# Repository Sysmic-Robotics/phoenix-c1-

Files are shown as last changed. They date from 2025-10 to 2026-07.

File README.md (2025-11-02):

# Phoenix-C1 — Driver modular para motor PMSM (RoboCup SSL)

Proyecto ELO301 — Sysmic Robotics  
Controlador modular para cada motor del robot, con ruta de actualización a FOC y mantenimiento sencillo en competencia. :contentReference[oaicite:0]{index=0}

---

## Estado del proyecto
- ✅ **Esquemáticos**: prácticamente completos; arquitectura modular por motor.
- 🚧 **PCB/Firmware**: siguiente hito inmediato (ver Cronograma del documento).
- 🎯 **Objetivo de costo**: ~20–30 USD/unidad (FOC-capable). :contentReference[oaicite:1]{index=1}

---

## Motivación y alcance
La placa “todo-en-uno” actual es frágil: una falla deja inoperante el sistema. Phoenix-C1 separa el control por motor para elevar confiabilidad, facilitar recambios y habilitar control avanzado (FOC) más adelante. :contentReference[oaicite:2]{index=2} :contentReference[oaicite:3]{index=3}

---

## Arquitectura del sistema (resumen)
- **MCU**: STM32G431CBU6 (control + PWM).
- **Gate driver**: DRV8323S.
- **Etapa de potencia**: 3 medios puentes con 6× MOSFET NTMFS5C612NLT1G.
- **Encoder**: AS5600 (I²C).
- **Alimentación lógica**: 3.3 V (buck).
- **Bus de potencia**: +V 10–40 V (diseño), pensado para baterías 6S/24 V del robot. :contentReference[oaicite:4]{index=4} :contentReference[oaicite:5]{index=5}

**Interfaces clave**
- I²C (AS5600), SPI (config/telemetría DRV8323S), SPI esclavo para consignas externas, PWM hacia DRV8323S, GPIO/EXTI y LED de estado. :contentReference[oaicite:6]{index=6}

---

## Firmware (V1)
- **Lazo**: control básico de velocidad con realimentación del encoder.
- **FOC**: previsto para actualización de firmware futura (hardware ya cableado). :contentReference[oaicite:7]{index=7}

**Módulos**
- Referencia/entrada (SPI esclavo), adquisición de velocidad (AS5600), generador PWM (TIMx), driver DRV8323S (config y fallas), temporización/SysTick. :contentReference[oaicite:8]{index=8}

**Flujo**
1. Init de periféricos (GPIO, TIM, I²C/SPI, PWM, DRV8323S deshabilitado).
2. Espera de referencia válida (sondeo cada 0.5 ms).
3. Lectura de velocidad (encoder).
4. Cálculo de control y actualización de duty en 3 fases.
5. Conmutación vía DRV8323S y realimentación. :contentReference[oaicite:9]{index=9}

---

## Pruebas planificadas
- **Elementos**: power-up +V∈[10,40] V, 3.3 V estable, rizado a f_PWM, separación de masas; validación SPI/I²C/PWM/GPIO. :contentReference[oaicite:10]{index=10}  
- **Funcionalidades**: arranque y control de velocidad; inyección de fallas (UVLO, nFAULT, kill-switch) y recuperación segura. :contentReference[oaicite:11]{index=11}

---

## Restricciones físicas y entorno
- **PCB** máx. 4×4 cm (montaje en el centro de motores ∅≈5 cm tipo 5010).  
- **Rango térmico** típico de competencias indoor; tolerancia a impactos moderados (carcasa plástica/impresa 3D). :contentReference[oaicite:12]{index=12}

---

## Costos (referencia)
- Meta ≈ 20–30 USD/unidad con capacidad FOC (24 drivers totales objetivo). :contentReference[oaicite:13]{index=13}  
- **BOM parcial** (ejemplo en CLP con 6 MOSFET): STM32G431, DRV8323S, NTMFS5C612NLT1G×6, AS5600, MAX15062 buck, PCB 4 capas, pasivos. :contentReference[oaicite:14]{index=14}

---

## Puesta en marcha (high-level)
1. Ensamblar y verificar 3.3 V, continuidad y ausencia de cortos.
2. Flashear firmware base (SWD/J-Link/ST-Link).
3. Probar SPI con DRV8323S (ID y registros), lectura AS5600 y PWM.  
4. Activar control de velocidad con consignas de prueba (escalón/rampa). :contentReference[oaicite:15]{index=15}

---

## Equipo
- Rodrigo Sierra, Gabriel Arcaya, Sebastián Pinochet — ELO301 (UTFSM). :contentReference[oaicite:16]{index=16}

---

## Licencia
Define la licencia aquí (MIT/BSD/GPL) según necesidades del curso/proyecto.

---

## Agradecimientos
Cátedra ELO301 y referentes tecnológicos (p. ej., drivers FOC comerciales tomados como benchmark de costo/desempeño). :contentReference[oaicite:17]{index=17}

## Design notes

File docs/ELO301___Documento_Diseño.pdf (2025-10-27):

Departamento de Electrónica Universidad Técnica Federico Santa María

# Documento de Diseño

# “Phoenix-C1” — Control de motor AC

## Proyecto ELO301

Fecha | Revisión | Autor | Comentarios
03/10/2025 | 1.0 | Rodrigo Sierra, Sebastián Pi-nochet, Gabriel Arcaya | Primera versión del documento de diseño.

## Índice general

1. Introducción | 3
2. Funcionalidades identificadas | 3
3. Elementos identificados | 3
4. Diseño de hardware propuesto | 4
4.1. Diagrama de bloques | | 4
4.2. Detalle por bloque | | 5
5. Diseño de firmware propuesto | 6
5.1. Detalle de drivers | | 6
5.2. Diagrama de flujo | | 6
5.3. Detalle por módulo | | 7
6. Pruebas | 8
6.1. Prueba sobre elementos | | 8
6.2. Prueba sobre funcionalidades | | 8
7. Cronograma | 9
8. Costos | 9

## Índice de imágenes

1. | Diagrama de bloques | | 5
2. | Diagrama de Flujo para el firmware | | 7

## 1. Introducción

El proyecto aborda la mejora del sistema de control de motores en un robot de competencia de la categoría RoboCup SSL. La arquitectura vigente integra en una única placa maestra la CPU, los giroscopios, los drivers de potencia, el módulo de radio y la gestión de energía, configuración que ha demostrado ser frágil: la falla o el desplazamiento de un componente compromete la operatividad completa de la placa. Para mitigar este riesgo, se propone una estrategia de modularización en la cual cada motor dispone de una placa de control independiente. Esta aproximación eleva la confiabilidad, facilita el mantenimiento en competencia y habilita la adopción progresiva de esquemas de control avanzados.
En una primera etapa, se priorizará el uso de un encoder magnético para implementar un lazo de control de velocidad simple y confiable. En paralelo, se dejarán previstas las conexiones físicas (sensado de corrientes y voltajes de fase, referencias de posición y sincronía, e interfaces de comunicación pertinentes) con el fin de habilitar, mediante una futura actualización de firmware, la implementación de control orientado por campo (FOC) sobre motores síncronos de imanes permanentes (PMSM), mejorando el desempeño dinámico y la eficiencia del actuador.

## 2. Funcionalidades identificadas

A partir del análisis del marco de referencia y de las correcciones al documento de especificaciones, se identifican las siguientes funcionalidades requeridas:
Sensado de velocidad y/o posición mediante encoder (preferentemente magnético).

Conmutación trifásica mediante driver de compuerta para MOSFET.

Control básico para el accionamiento de un PMSM con posibilidad de evolución a FOC.

Interfaces de comunicación SPI para enlace con una unidad central.

Capacidades de diagnóstico: monitoreo de corrientes de fase y tensión de alimentación.

## 3. Elementos identificados

Para materializar las funcionalidades anteriores, se identifican los siguientes elementos de diseño y hardware:
Controlador principal: microcontrolador de la familia STM32 para lazo de control y comunicaciones.

Etapa de potencia: puente trifásico con MOSFET y driver de compuerta dedicado.

Sensado: resistencias shunt para corriente y encoder magnético para posición/velocidad.

Alimentación y protección: convertidores DC–DC para rieles lógicos y salvaguardas frente a sobrecorriente/sobretensión.

Comunicación: conectividad externa mediante SPI hacia la CPU principal.

Firmware: algoritmo de control para PMSM con ruta de actualización hacia FOC y parametrización en campo.

## 4. Diseño de hardware propuesto

### 4.1. Diagrama de bloques

El sistema se organiza en dos dominios: control y sensado (lógica a +3,3 V) y potencia (bus +V puede ser entre 10V a 40V). El microcontrolador STM32G431CBU6 coordina la conmutación del inversor trifásico y la adquisición de señales. La etapa de potencia la componen el gate driver DRV8323S y seis MOSFET NTMFS5C612NLT1G en tres medio-puentes que alimentan un PMSM. La corriente de fase se mide con un resistor shunt de baja impedancia en el retorno. Un AS5600 entrega la posición del rotor por bus I²C.

Buses y direcciones de señal:
I

2C bidireccional (ENC SDA, ENC SCL): el MCU actúa como maestro y el codificador AS5600 como esclavo; el flujo útil de datos es sensor→MCU.

SPI con roles diferenciados:
- DRV8323S (MCU maestro): SPI MOSI (MCU→DRV), SPI MISO (DRV→MCU), SPI SCK (MCU→DRV), GD CS (MCU→DRV, activo-bajo). Uso: configuración, telemetría y diagnóstico de fallas.
- Conector de referencia de velocidad (MCU esclavo): REF MOSI (Maestro externo→MCU), REF MISO (MCU→Maestro externo), REF SCK (Maestro externo→MCU), REF CS (Maestro externo→MCU, activo-bajo). Uso: recepción de consignas y, opcionalmente, envío de telemetría bajo petición.

PWM unidireccional (MOTOR1, MOTOR2, MOTOR3) desde el MCU hacia el DRV8323S para la modulación
de compuertas (p. ej., SVPWM).

GPIO/EXTI: líneas INT1 y INT2 reservadas para interrupciones de eventos externos; salida LED para señalización de estados.

Dominio de potencia: el Power Supply Connector entrega el bus +V a la etapa de potencia y a la entrada del Power Management (Buck), que regula a +3,3 V para lógica, sensores y señales de control, separando los dominios de potencia y lógica.

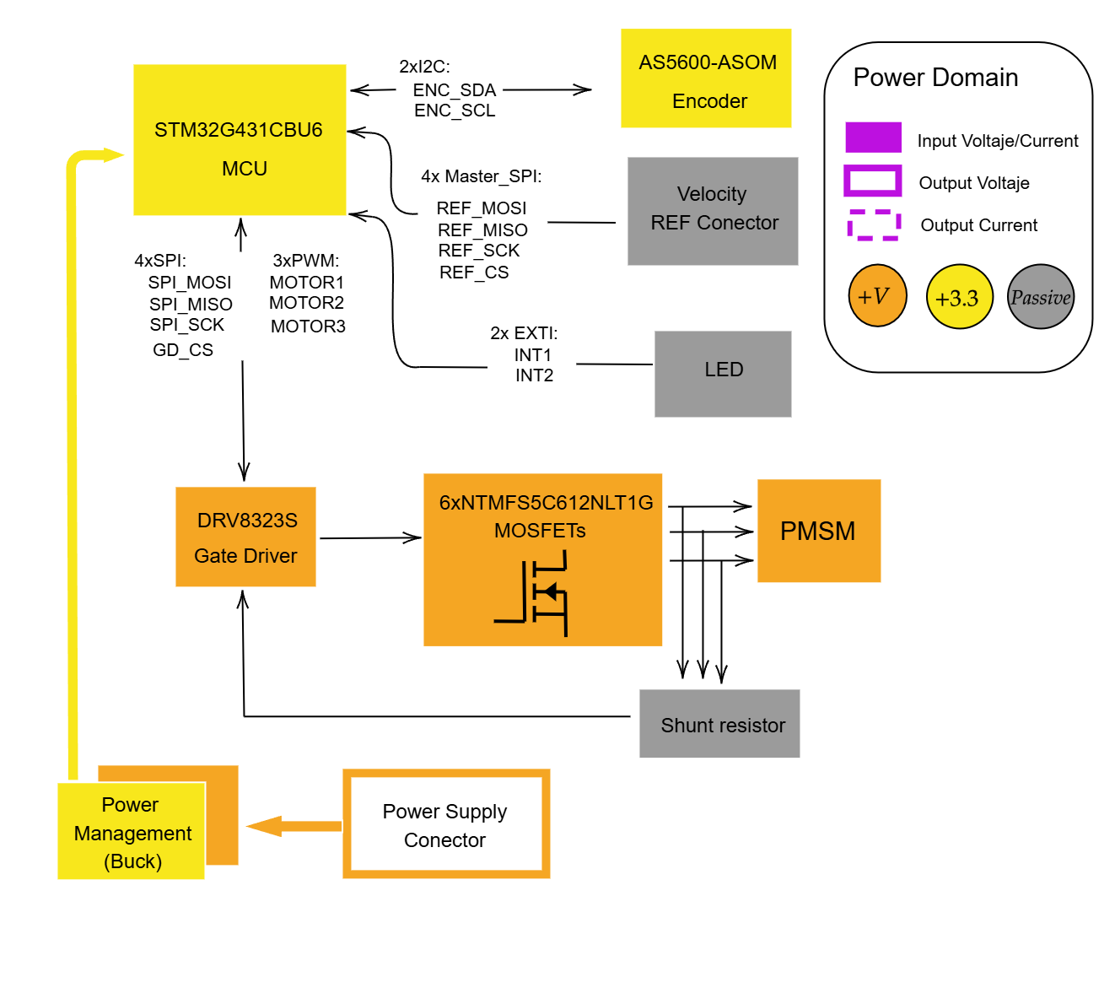
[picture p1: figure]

Illustration 1: Diagrama de bloques

### 4.2. Detalle por bloque

Bloque 1: Control y sensado (MCU, AS5600 e interfaces) El STM32G431CBU6 genera tres señales PWM (MOTOR1{3) para accionar el inversor a través del DRV8323S. Mantiene dos enlaces SPI con roles diferenciados: (i) MCU como maestro hacia el DRV8323S
SPI MOSI, SPI MISO, SPI SCK, GD CS
para configuración y diagnóstico; (ii) MCU como esclavo en el bus de referencia de velocidad
REF MOSI (entrada al MCU), REF MISO (salida del MCU), REF SCK (entrada), REF CS (entrada activabaja)
, donde un maestro externo envía consignas. La posición/velocidad del rotor se adquiere por un bus I²C bidireccional con el AS5600

ENC SDA, ENC SCL
, operando el MCU como maestro. Además, se disponen dos líneas de interrupción externa

INT1, INT2
para eventos asincrónicos y una salida LED para señalización de estado. Todo el bloque funciona a +3,3 V provistos por el regulador buck.

Bloque 2: Potencia y conversión de energía (DRV8323S, MOSFETs, PMSM y alimentación) El DRV8323S recibe las señales PWM del MCU y conmuta seis MOSFET NTMFS5C612NLT1G dispuestos en tres medio-puentes para conformar un inversor trifásico que alimenta el PMSM. El gate driver gestiona la habilitación, los tiempos muertos y la protección, y expone el estado por SPI y/o pines de falla dedicados. El Power Supply Connector introduce el bus +V a la etapa de potencia y al Power Management (Buck), que regula a +3,3 V para la electrónica de control, manteniendo separados los dominios de potencia y lógica.

Bloque 3: Sensado de corriente (hardware presente; deshabilitado en esta versión) El trayecto de sensado de corriente mediante resistor shunt y acondicionamiento analógico se encuentra implementado a nivel de hardware y cableado al DRV8323S/ADC del MCU. No obstante, no será utilizado por el firmware inicial: por restricciones de tiempo no se implementará control FOC ni lazos de corriente (ni id ni iq). La primera versión ejecutará control simple de velocidad basado únicamente en realimentación del encoder. El sensado de corriente y el FOC quedarán planificados como actualización futura del firmware, reutilizando el hardware existente sin cambios en la placa.

## 5. Diseño de firmware propuesto

### 5.1. Detalle de drivers

El firmware se organiza en controladores de bajo nivel asociados a cada elemento del sistema: Driver de comunicaciones para referencia: módulo de recepción de consignas desde el exterior. Entrega una bandera de referencia válida y el valor de consigna.

Temporización: temporizador/SysTick para retardos y planificación de tareas; se utiliza un sondeo con espera de 0,5 ms cuando no hay referencia disponible.

Encoder: adquisición de posición/velocidad del motor a través del sensor de posición. Expone la velocidad filtrada al lazo de control.

Driver PWM (TIMx): generación de tres salidas PWM para el inversor trifásico. Permite habilitar/deshabilitar el puente y actualizar el ciclo útil en tiempo real.

Driver del gate driver (DRV8323S): interfaz de configuración y diagnóstico del controlador de compuertas; aplica las órdenes de encendido/apagado y supervisa el estado de fallas.

Driver de GPIO de estado: control de indicadores (LED) y líneas de interrupción si corresponde.

### 5.2. Diagrama de flujo

El flujo funcional se resume en los siguientes pasos:
1. Inicio: inicialización de temporizadores, GPIO, comunicaciones, encoder, PWM y gate driver (salidas deshabilitadas).
2. Recepción de referencia: si no existe una referencia válida, se espera 0,5 ms y se repite el sondeo.
3. Lectura de velocidad: una vez disponible la referencia, se obtiene la velocidad del motor desde el encoder.
4. Cálculo en STM32: se ejecuta el cómputo de variables de control y se determina el ciclo útil de PWM para las tres fases.
5. Accionamiento: se actualizan las salidas PWM; el gate driver DRV8323S conmuta los MOSFET del inversor.
6. Ejecución y realimentación: el motor gira, se cierra el bucle mediante la nueva lectura del encoder y se regresa al paso de cálculo.

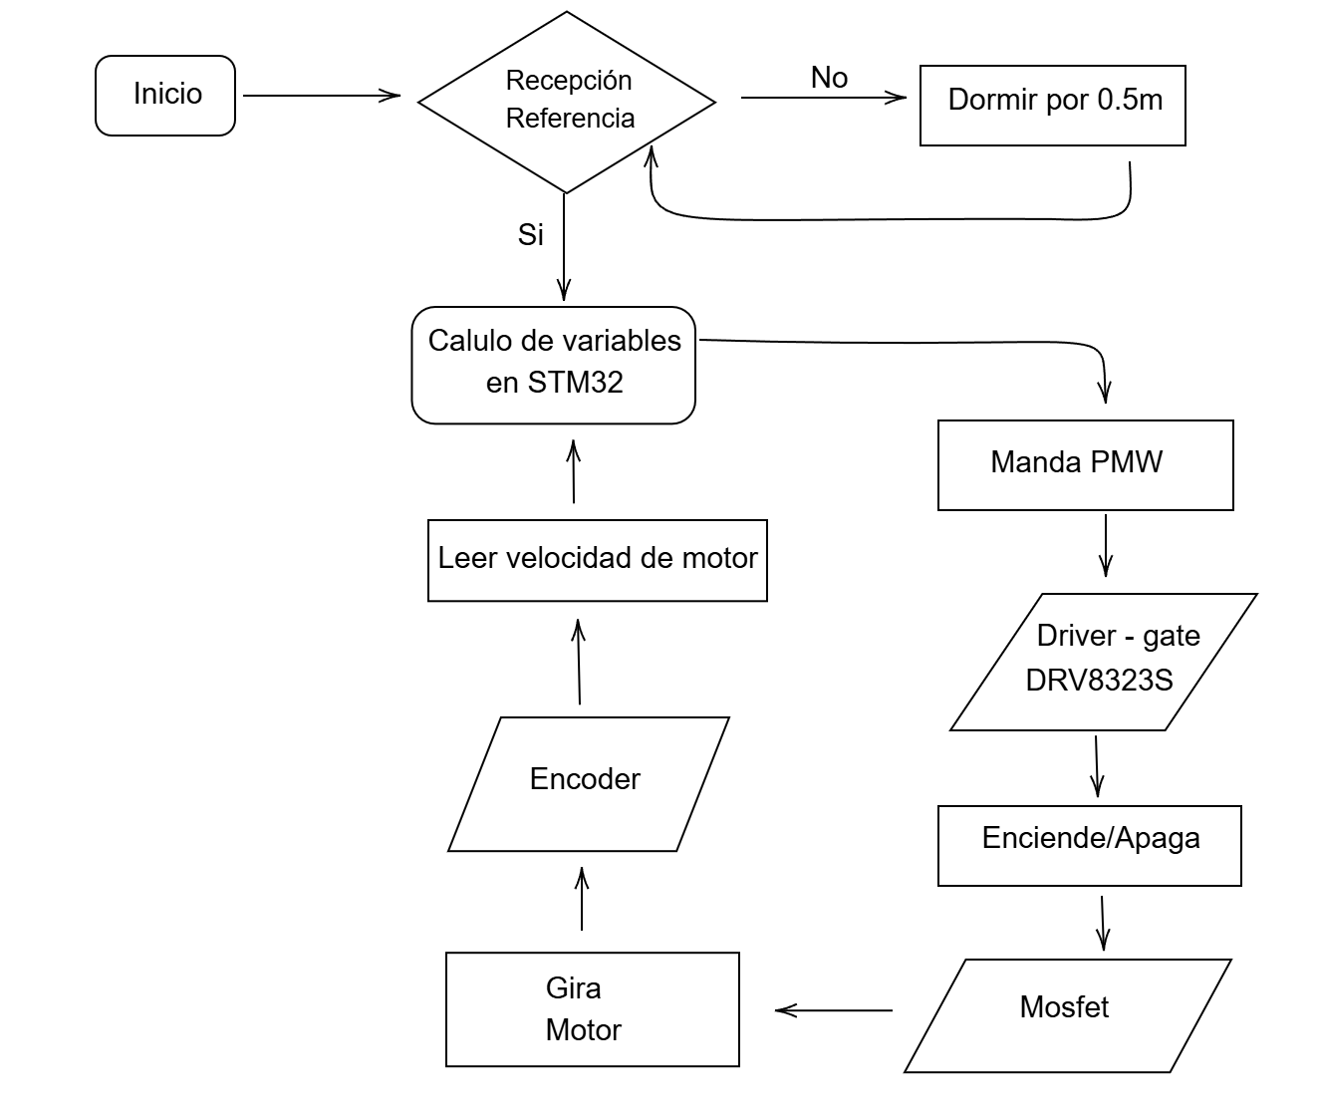
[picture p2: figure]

Illustration 2: Diagrama de Flujo para el firmware

### 5.3. Detalle por módulo

Módulo 1: Adquisición y referencia Este módulo gestiona la llegada de la consigna externa y la medición de la velocidad del motor. Implementa el sondeo con espera de 0,5 ms cuando no hay referencia, convierte la posición del encoder en velocidad utilizable por el control y publica los datos al scheduler. Sus principales interfaces son: entrada de Referencia (comunicación), entrada de Encoder y salida de Velocidad estimada más la bandera de Referencia válida.

Módulo 2: Control y actuación Este módulo ejecuta el cálculo en el STM32 para obtener el ciclo útil de las tres fases y actualiza el generador PWM. Coordina el encendido/apagado del gate driver DRV8323S y, por ende, la conmutación de los MOSFET. Sus interfaces son: entradas de Referencia y Velocidad, salidas PWM A/B/C hacia el gate driver y líneas de estado/diagnóstico para supervisión.

## 6. Pruebas

### 6.1. Prueba sobre elementos

Prueba 1 Integridad eléctrica y alimentación. Se alimenta el bus +V ∈ [10, 40] V y se verifica la regulación de +3,3 V en arranque y régimen, el rizado a la frecuencia fPWM y la correcta separación de masas de potencia y lógica; como metas prácticas se considera V3,3.

Prueba 2 Interfaces digitales y señalización. Se valida el SPI con el DRV8323S (MCU como maestro: lectura/escritura de registros, ID y banderas), el SPI de referencia (MCU como esclavo: REF CS activo-bajo, recepción de consignas), el I²C con el AS5600 (lectura de ángulo/velocidad), la generación PWM (frecuencia y resolución) y las GPIO/EXTI de estado.

### 6.2. Prueba sobre funcionalidades

Prueba 1 Arranque y control de velocidad en lazo cerrado sin FOC. Con el DRV8323S habilitado, se aplican referencias tipo escalón y rampa dentro del rango operativo, registrando referencia, velocidad del encoder, ciclo útil y estado del driver para distintos niveles de +V .

Prueba 2 Gestión de fallas y seguridad funcional. Se induce UVLO, se fuerza nFAULT y se acciona el kill-switch lógico para comprobar deshabilitación inmediata de PWM, registro/notificación de la causa y recuperación controlada.

## 7. Cronograma

El cronograma se compacta en cuatro bloques quincenales más la entrega aproximada, cubriendo desde el 13 de octubre hasta el 1 de diciembre de 2025. Las columnas representan ventanas de trabajo con solapamientos controlados.

13–26 Oct | 27 Oct–9 Nov | 10–23 Nov | 24–30 Nov | 1 Dic

Diseño
esquemático

X

Diseño PCB | X | X

Compra
componentes
| X

Compra y envío de
PCB
| X
Integración | X | X

Desarrollo
firmware
| X | X | X
Pruebas | X | X

Documentación y
entrega
| | | X | X

Tabla 1: Cronograma compacto hasta la entrega del 1 de diciembre de 2025.

## 8. Costos

Descripción (por driver) | 1 unidad [CLP] | 100 unidades [CLP]
STM32G431CBU6 (1×) | $5,667 | $361,800
DRV8323S (gate driver, 1×) | $3,998 | $248,600
NTMFS5C612NLT (MOSFET, 6×) | $13,374 | $636,600
AS5600–ASOM (encoder, 1×) | $3,192 | $208,300
MAX15062BATA+T (dc-dc buck, 1×) | $2,442 | $189,300
PCB 4×4 cm, 4 capas + envío (1×) | $10,000 | $1,000,000
Pasivos y reguladores (R, C, etc.) | $3,000 | $300,000
Total (BOM parcial) | $41,673 | $2,944,600

Tabla 2: Costos por componente en CLP. Los valores provienen de Mouser y consideran 6 MOSFET por driver. Proyección lineal a 100 unidades, con descuentos por volumen.

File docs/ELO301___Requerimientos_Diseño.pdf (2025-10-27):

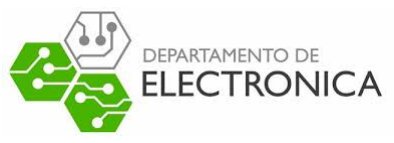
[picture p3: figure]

# Documento de Especificaciones

## Control de motor AC

## Fecha 23 de octubre de 2025 Integrantes: Rodrigo Sierra Gabriel Arcaya Sebastian Pinochet Asignatura: ELO301 Profesor: Alvaro Aguirre ´

## Índice

1 Identificación del cliente | 4
2 Nombre del Equipo | 4
3 Marco de Referencia | 4
4 Funcionalidad requerida y/o identificada | 4
5 Alimentación Utilizada | 5
6 Empaquetamiento del equipo | 5
7 Características del Medio donde Será Utilizado | 6
8 Costos Objetivos del Proyecto | 6
9 Certificaciones a Cumplir | 6
10 Requerimientos Especiales | 6

ELO301 | 2025

## Registro de Especificaciones

Nombre del Proyecto: Control Motor AC

Fecha | Revisión | Autor | Comentarios
29/08/2025 | 1.0 | Rodrigo Sierra, Gabriel Arcaya, Sebastián Pinochet | Revisión inicial
USM | 3

## 1. Identificación del cliente

### 1.1. Fecha del Requerimiento

La fecha de cumplimiento del requerimiento se establece para el final del semestre académico, lo que corresponde aproximadamente a un plazo de 14 semanas.

### 1.2. Nombre del mandante

Alvaro Aguirre

### 1.3. Persona de contacto

Alvaro Aguirre

### 1.4. Datos de contacto

alvaro.aguirre@gmail.com

## 2. Nombre del Equipo

Sysmic Robotics

## 3. Marco de Referencia

El problema identificado corresponde a la mejora del sistema de control de los motores de un robot de competencia de la categoría RoboCup SSL. En la actualidad, se utiliza una placa maestra que integra en un único circuito la CPU, los giroscopios, los drivers de potencia, el módulo de radio y la gestión de energía. Esta arquitectura monolítica ha generado dificultades en el montaje y mantenimiento, dado que la falla o el desplazamiento de un solo componente inutiliza la totalidad de la placa, dejándola inoperante y no apta para la competencia.

Con el fin de superar estas limitaciones, se propone una estrategia de modularización, en la cual cada motor contará con una placa independiente para su control. Esta aproximación permite aumentar la confiabilidad del sistema y, al mismo tiempo, ofrece la oportunidad de implementar un esquema de control más preciso. En particular, se plantea el uso de motores PMSM controlados mediante la técnica de Control Orientado por Campo (FOC), la cual garantiza un desempeño dinámico superior y un mayor aprovechamiento de las capacidades del actuador.

## 4. Funcionalidad requerida y/o identificada

### 4.1. Principales funcionalidades que debe cumplir el sistema

El sistema debe garantizar un control robusto y eficiente de los motores del robot de competencia, asegurando estabilidad y confiabilidad en escenarios de alta exigencia como la RoboCup SSL. Las principales funcionalidades requeridas son:

Sensado de velocidad mediante un encoder.

Utilización de un driver para la conmutación de MOSFET.

Control básico para lograr movimiento de un motor síncrono de imanes permanentes (PMSM) con posibilidad de mejora futura a control basado en campo (FOC).

Interfaz de comunicación SPI y UART para posibilidad de comunicación con una unidad central.

Capacidad de diagnóstico básico (monitoreo de corriente y voltaje).

### 4.2. Principales elementos que debe incorporar el sistema

Para cumplir las funcionalidades definidas, el sistema debe integrar los siguientes elementos físicos y de diseño:

Controlador principal: basado en microcontrolador STM32 para control de motores.

Etapa de potencia: puente trifásico con MOSFETs y drivers de compuerta dedicados.

Sensado: sensores de corriente (shunt) y sensores de posición (encoder magnético).

Alimentación: convertidores DC-DC y sistema de protección.

Comunicación: Posibilidad de comunicación externa con interfaz estándar (SPI, UART) para una CPU principal.

Firmware: Algoritmo básico para la generación de movimiento en un motor síncrono de imanes permanentes (PMSM, Permanent Magnet Synchronous Motor ), con la posibilidad de una futura implementación de control por orientación de campo (FOC) y ajuste de parámetros.

## 5. Alimentación Utilizada

La alimentación del sistema se establece en 24 V, correspondiente al voltaje utilizado en la placa principal. Además, se emplean baterías con características similares, cuya tensión nominal es de 22, 2 V. En particular, se consideran dos modelos principales, entre ellos la batería CNHL de 22, 2 V, 100C, 6s, con una capacidad de 1300 mAh y una energía de 28, 86Wh.

## 6. Empaquetamiento del equipo

### 6.1. Límites de Tamaño

El equipo ”Sysmic Robotics”decidió reemplazar los motores EC-45 de Maxon debido a su alto costo, priorizando la reducción de gastos de producción frente a la categoría SSL. Como alternativa, se seleccionaron motores brushless de imanes permanentes adquiridos en AliExpress (modelos 5010 de 360KV y 750KV, costo aproximado de 16 USD), originalmente diseñados para multicópteros. Con un diámetro cercano a 5 cm, estos motores imponen la restricción de diseñar el driver con dimensiones máximas de 4 × 4 cm para su instalación en el centro del motor.

### 6.2. Grado de Protección

El sistema debe disponer de un nivel de protección adecuado que garantice su funcionamiento en entornos de competencia:

Protección mecánica: Se considera suficiente un encapsulado que prevenga daños ocasionados por golpes o vibraciones.

### 6.3. Geometría del Equipo

La geometría se define por las dimensiones y el volumen ocupado por el sistema. En dispositivos de control para robots de competencia se consideran:

Dimensiones del PCB: tamaño máximo de 4 × 4 cm para permitir su montaje en el centro del motor.

Espesor: placas de 1,6 mm con posibilidad de 4 capas de cobre.

Forma: diseño cuadrado que facilite una sujeción firme mediante tornillos al sistema.

Conectividad: conectores laterales que faciliten el cableado interno del robot.

### 6.4. Materiales a Utilizar

La selección de materiales debe asegurar resistencia mecánica, estabilidad térmica y buena conductividad eléctrica. Para este tipo de sistemas se consideran:

Sustrato de PCB: FR4 de alta calidad para aplicaciones electrónicas estándar.

Cobre: espesor de 1 oz/ft² para las pistas de potencia.

Carcasa: estructura plástica ligera PLA impreso en 3D para el montaje.

### 6.5. Interfaz Física con el Usuario

La interfaz física debe permitir la interacción básica entre el operador y el sistema de control del motor, facilitando el montaje, configuración y monitoreo en condiciones de competencia. Los elementos considerados son:

Conectores de potencia: terminales para la conexión de las baterías de 24 V y de las fases del motor PMSM.

Conectores de señal: pines o headers dedicados para comunicación con la CPU principal (SPI, UART).

Pads de programación: interfaz física para grabar o depurar el firmware (ej. SWD o JTAG).

## 7. Características del Medio donde Será Utilizado

### 7.1. Temperatura Ambiental

El sistema debe operar en condiciones de temperatura moderada, típicas de entornos cerrados donde se desarrollan las competencias RoboCup. Se considera un rango de funcionamiento entre 10◦C y 40◦C, con tolerancia a incrementos locales debido a la disipación térmica de los componentes electrónicos.

### 7.2. Golpes y Vibraciones

El dispositivo debe soportar impactos moderados derivados de choques entre robots o con el balón, habituales en el contexto competitivo. Se considera el uso de carcasa protectora de plástico ABS o impresión 3D en PLA reforzado, capaz de absorber energía de impacto sin comprometer el funcionamiento electrónico.

## 8. Costos Objetivos del Proyecto

El equipo indicó que el costo aproximado de producción de un driver basado en el integrado L623SPD es de 18 USD; sin embargo, dicho diseño no cumple con el desempeño esperado. Como referencia tecnológica se considera el módulo Moteus C1, que implementa control FOC, aunque su precio de adquisición es de 70 USD por unidad, lo cual resulta poco viable económicamente.
En este contexto, el objetivo del proyecto es desarrollar un driver con capacidad de control FOC cuyo costo de producción se sitúe en torno a los 20 ∼ 30 USD por unidad. Esta meta responde a la necesidad de fabricar un total de 24 drivers (cuatro por cada robot), considerando un mínimo de seis robots en operación. Alcanzar este umbral de costos permitirá mantener la competitividad frente a equipos rivales que emplean componentes de menor precio, sin comprometer el rendimiento requerido en competencia.

## 9. Certificaciones a Cumplir

Dado que el presente desarrollo corresponde a un producto de carácter experimental y de testeo, no se priorizará la obtención formal de certificaciones. Sin embargo, el diseño del driver tomará como referencia normativas y buenas prácticas de seguridad eléctrica y compatibilidad electromagnética, con el fin de asegurar un nivel básico de robustez y confiabilidad.

## 10. Requerimientos Especiales

Además de los criterios funcionales básicos, el sistema debe contemplar requerimientos adicionales que faciliten su operación y mantenimiento en el entorno de competencia:

Mantenimiento rápido: facilidad de reemplazo de módulos en caso de falla durante el torneo.

Modularidad: independencia de cada driver para minimizar el impacto de fallas aisladas.

Protección eléctrica: detección de sobrecorriente y sobretensión para prevenir daños en el motor y la electróni-ca.

Interfaz de depuración: acceso a pads o conectores para reprogramación y diagnóstico rápido.

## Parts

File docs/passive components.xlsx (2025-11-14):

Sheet: Revision Componentes
 |  |  |  |  |  |  |  |  |  |  |  |  |  |  |  |  |  |  |  | TOTAL(USD) | TOTAL(CLP)~
power input |  |  |  |  |  |  |  |  |  |  |  |  |  |  |  |  |  |  |  | 25.51 | 27794
gate driver
h bridge A | x3 | COMPONENTES | Power Input(MAX15062AATA+T ) | Gate Driver | H bridges | Current Sense | Led Sense | Bulk capacitance | AS5600 ASOM | COMPONENTES | Tipo | Part Number | Altium | Library Footprint | Sch Corregido | FP Corregido | Cantidad | Link | Precio unitario(USD) | CantX$(USD) | CantX$(CLP)
current sense |  | XT30PW-M | 1 |  |  |  |  |  |  | MAX15062AATAT | BUCK | MAX15062AATAT | X | 8-TDFN | X | X
aux 2 |  | 1uf 100v | 1 |  |  |  |  |  |  | 1000pf 6.3V | CAPACITOR | 08056C102JAT2A | X | C0805 - KYOCERA | X | X | 3 | Mouser (https://mou.sr/47cPcHL) | 0.1 | 0.3 | 282.555
aux 1 |  | 1uf | 2 | 2 |  |  |  |  |  | 1uf 6.3V | CAPACITOR | 08056C105MAT2A | X | C0805 - KYOCERA | X | X | 4 | Mouser (https://mou.sr/3JzqjNg) | 0.34 | 1.36 | 1280.916
LED SENSE |  | 33 uh | 1 |  |  |  |  |  |  | 47nf 100v | CAPACITOR | C0603X473K1RACTU | X | C0603 - KEMET | X | X | 1 | Mouser (https://mou.sr/47aSprm) | 0.44 | 0.44 | 414.414
BUCK capacitance |  | SMBJ48D-M3/1 | 1 |  |  |  |  |  |  | 1uf 25v | CAPACITOR | C1608X7R1E105K080AE | X | C0603 - MURATA | X | X | 1 | Mouser (https://mou.sr/43ubkLk) | 0.24 | 0.24 | 226.044
 |  | 1uf 25v |  | 1 |  |  |  |  |  | 0.1uf 100v | CAPACITOR | GCJ188R72A104KA01D | X | C0603 - MURATA | X | X | 1 | Mouser (https://mou.sr/47GKd25) | 0.16 | 0.16 | 150.696
 |  | 0.1uf 100v |  | 1 | 3 |  |  |  |  | 1uf 100v | CAPACITOR | GCM21BC72A105KE36L | X | C0805 - MURATA | X | X | 4 | Mouser (https://mou.sr/4oCNLrW) | 0.42 | 1.68 | 1582.308
 |  | 47nf 100v |  | 1 |  |  |  |  |  | 4.7uf 100v | CAPACITOR | GRJ31CC72A475KE01K | X | C1206 - MURATA | X | X | 12 | Mouser (https://mou.sr/3WUpj9x) | 0.8 | 9.6 | 9041.76
 |  | 2k Ohm |  | 2 |  |  |  |  |  | 100nf 20% | CAPACITOR | GRM022R60J104ME15L | X | C01005-MURATA | X | X | 2 | Mouser (https://mou.sr/4owREP0) | 0.1 | 0.2 | 188.37
 |  | TPN19008QM_LQ |  |  | 6 |  |  |  |  | 4.7uF 6.3V | CAPACITOR | GRM035R60J475ME15D | X | C0201 - MURATA | X | X | 1 | https://www.mouser.cl/ProductDetail/Murata-Electronics/GRM035R60J475ME15D?qs=I53XXhTNm8vhFCgPvCZ%252BPQ%3D%3D |  | 1 | 941.85
 |  | 2m Ohm |  |  | 3 |  |  |  |  | 10uf | CAPACITOR | GRM155R60J106ME05D | X | C0402 - MURATA | X | X | 3 | Mouser (https://mou.sr/4qt9N1T) | 0.1 | 0.3 | 282.555
 |  | BAT41KFILM |  |  | 3 |  |  |  |  | 1uF 6.3V | CAPACITOR | GRM188R60J105KA01D | X | C0603 - MURATA | X | X | 1 | https://www.mouser.cl/ProductDetail/Murata-Electronics/GRM188R60J105KA01D?qs=dddcrN876Gomyq%2FPjh7oaA%3D%3D |  | 1 | 941.85
 |  | 22 Ohm |  |  |  | 3 |  |  |  | 0.1 uF 6.3 V | CAPACITOR | GRT033R60J104KE01J | X | C0201 - MURATA | X | X | 5 | https://www.mouser.cl/ProductDetail/Murata-Electronics/GRT033R60J104KE01J |  | 5 | 4709.25
 |  | 1000pf |  |  |  | 3 |  |  |  | XT30PW-M | CONNECTOR | XT30PW-M | X | CONN - XT30PW | X | X |  |  | 0.9 |  | 942
 |  | 560 Ohm |  |  |  |  | 2 |  |  | LED ROJO | DIODO | APT1608SURCK | X | LED0603 - KINGBRIGHT | X | X | 2 | Mouser (https://mou.sr/47slRYu) | 0.41 | 0.82 | 772.317
 |  | LED |  |  |  |  | 2 |  |  | BAT41KFILM | DIODO | BAT41KFILM | X | DSOD-523 - STMicroelectronics | X | X |  | Mouser (https://mou.sr/42XoOiu) | 0.34 | 0.34 | 320.229
 |  | 4.7uf 100v |  |  |  |  |  | 12 |  | SMBJ48D-M3/1 | DIODO | SMBJ48D-M3/I | X | DDO-214AA (SMBJ) - VISHAY | X | X |  | Mouser (https://mou.sr/3Wle1em) | 0.34 |  | 941.85
 |  | 100nf 20% |  |  |  |  |  |  | 1 | DRV823 | DRIVER | DRV823 | X | 40-WQFN - TEXAS | X | X
 |  | 10uf | 1 |  |  |  |  |  | 1 | AS5600-ASOM | ENCODER | AS5600-ASOM | X | SOIC-8 - OSRAM | X | X
 |  | 4.7kOhm |  |  |  |  |  |  | 2 | 3.3 uh | INDUCTOR | LPS4018-333MRC | X | L1515 - COILCRAFT | X | X |  |  | 1.59 | 1.59 | 1497.5415
 |  |  |  |  |  |  |  |  |  | STM32G4 | MCU | STM32G4 | X | 48-UFQFN - STMicroelectronics | X | X |  |  |  |  | 941.85
 |  |  |  |  |  |  |  |  |  | TPN19008QM_LQ | MOSFET | TPN19008QM_LQ | X | 8-TSON - TOSHIBA | X | X |  | Mouser (https://mou.sr/3Jxp5Cd) | 1.11 |  | 941.85
 |  |  |  |  |  |  |  |  |  | 2k Ohm | RESISTOR | AF0402JR-072KL | X | R0402 - YAGEO | X | X |  | https://www.mouser.cl/ProductDetail/YAGEO/AF0402JR-072KL?qs=sGAEpiMZZMtlubZbdhIBIIzXXd8RXMQ1A4VeykjrMVQ%3D | 0.18 | 0.18 | 169.533
 |  |  |  |  |  |  |  |  |  | 2m Ohm | RESISTOR | CSSH0805FT2L00 | X | R0805 - SEI | X | X |  | Mouser (https://mou.sr/47oFwIR) | 0.6 | 0.6 | 565.11
 |  |  |  |  |  |  |  |  |  | 4.7kOhm | RESISTOR | RC0603FR-104K7L | X | R0603 - YAGEO | X | X | 1 | https://www.mouser.cl/ProductDetail/YAGEO/RC0603FR-104K7L?qs=sGAEpiMZZMtlubZbdhIBIHvQf5egq9lv0mk7h5hs6B0%3D | 0.32 | 0.32 | 301.392
 |  |  |  |  |  |  |  |  |  | 22 Ohm | RESISTOR | RC0603JR-0722RL | X | R0603 - YAGEO | X | X |  | Mouser (https://mou.sr/47bBWDf) | 0.15 | 0.15 | 141.2775
 |  |  |  |  |  |  |  |  |  | 560 Ohm | RESISTOR | RT0603BRD07560RL | X | R0603 - YAGEO | X | X |  | Mouser (https://mou.sr/48K3Qr8) | 0.23 | 0.23 | 216.6255

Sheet: Hoja1
Part Number (Design Item ID) | Tipo | Descripción corta | Nombre de librería sugerido (.SchLib) | Modificado | Grilla
SMBJ48D-M3/1 | Diodo TVS | Diodo TVS 48V unidireccional DO-214AA | TVS_48V_DO214AA - SMBJ48D-M3/1 | X
STM32G431CBU6 | Microcontrolador | STM32G431C8T6 UFQFPN48 32bit MCU | MCU_STM32G431_UFQFPN48 - STM32G431CBU6
MAX15062AATA+T | Convertidor DC-DC | Step-Down 600mA Síncrono | DC-DC_MAX15062_ATA - MAX15062AATA+T | X
XT60PW-M | Conector | Conector XT60 macho | Conn_XT60PW-M - XT60PW-M | X
RT0603BRD07650RL | Resistencia | 0603, 1%, 650Ω | Res_650_0603 - RT0603BRD07650RL | X
RC0603BR-104K7L | Resistencia | 0603, 5%, 100kΩ | Res_100K_0603 - RC0603BR-104K7L | X
CSSH0805FT2L00 | Resistencia shunt | 0805, 2mΩ, 1% | Res_Shunt_2m_0805 - CSSH0805FT2L00 | X
TPN19008QM_LQ | MOSFET | TSON 30V 3.8A | MOSFET_TSON_30V_3A - TPN19008QM_LQ | X
0603X473K1RACTU | Capacitor | 0603 0.047uF 100V | Cap_100V_0u047_0603 - 0603X473K1RACTU | X
0805GC102JAT2A | Capacitor | 0805 1nF 100V | Cap_100V_1n_0805 - 0805GC102JAT2A | X
0805GC105MAT2A | Capacitor | 0805 1uF 6.3V | Cap_6V3_1u_0805 - 0805GC105MAT2A | X
BAT41KFILM | Diodo Schottky | 200 mA 1 V SOD-523 | D_Schottky_200mA_1V_SOD523 - BAT41KFILM | X
MB6K1600BR3M | Puente rectificador | 3.3uH 20% 1MHz Metal 0603 | Ind_3u3_0603 - MB6K1600BR3M
AS5600-ASOM | Sensor | Sensor magnético de posición | Sensor_AS5600 - AS5600-ASOM | X
Conn_01x01 | Conector | Header 1x1 | Conn_1x1 - Conn_01x01 | X
LPS4018-333MR | Inductor | 33uH, 20% Ferrita, 1515 | Ind_33uH_1515 - LPS4018-333MR | X
DRV8323RSRTR | Driver | Driver 60V Trifásico 40-WQFN | Driver_3PH_DRV8323_WQFN - DRV8323RSRTR | X
CMP-17439-000151-1 | Conector | Header 5x5 1.5MM | Conn_Header_5x5_1.5MM - CMP-17439-000151-1 | X
GRJ31CC7ZAA475KE01K | Capacitor | 4.7uF, 100V, 1206 | Cap_100V_4u7_1206 - GRJ31CC7ZAA475KE01K | X
GRT033R60J104KE01J | Capacitor | 0.1uF, 6.3V, 0201 | Cap_6V3_0u1_0201 - GRT033R60J104KE01J | X
GCM21BC72A105KE36L | Capacitor | 1uF, 6.3V, 0805 | Cap_6V3_1u_0805 - GCM21BC72A105KE36L | X
GRM155R60J106ME05D | Capacitor | 10uF, 6.3V, 0402 | Cap_6V3_10u_0402 - GRM155R60J106ME05D | X
GRM033R60J474ME15D | Capacitor | 0.47uF, 6.3V, 0201 | Cap_6V3_0u47_0201 - GRM033R60J474ME15D | X
GRM188R60J105KA01D | Capacitor | 1uF, 6.3V, 0603 | Cap_6V3_1u_0603 - GRM188R60J105KA01D | X
GCJ188R72A104KA01D | Capacitor | 0.1uF, 100V, 0603 | Cap_100V_0u1_0603 - GCJ188R72A104KA01D | X
GRM022R60J104ME15L | Capacitor | 0.1uF, 6.3V, 01005 | Cap_6V3_0u1_01005 - GRM022R60J104ME15L | X
APT1608SURCK | LED | LED rojo 0603 | LED_Red_0603 - APT1608SURCK | X
AF024JR-0722KL | Resistencia | 22kΩ, 1%, 0603 | Res_22K_0603 - AF024JR-0722KL | X
RC0603JR-0722RL | Resistencia | 22Ω, 5%, 0603 | Res_22_0603 - RC0603JR-0722RL | X
XT30PW-M | Conector | XT30 macho | Conn_XT30PW-M - XT30PW-M | X
C1608X7R1E105K080AE | Capacitor | 1uF, 25V, X7R, 0603 | Cap_25V_1u_0603 - C1608X7R1E105K080AE | X
Arduino_PINS | Header simbólico | Pines para Arduino | Conn_Arduino_Header - Arduino_PINS | X
TH_UART | Header simbólico | Header para UART | Conn_UART_Header - TH_UART

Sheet: C.phoenix-c1 por modulo
Schematics
hbridgeA.SchDoc |  |  |  | power_input.SchDoc
Components | Value | Part number | Cantidad
MOSFET |  | TPN19008QM,LQ | 2
R | 2m Ω 1W | CSSH0805FT2L00 | 1
C | 0.1uF 100V | GCJ188R72A104KA01D | 1
D |  | BAT41KFILM | 1 | ports.SchDoc
hbridgeB.SchDoc
Components | Value | Part number | Cantidad
MOSFET |  | TPN19008QM,LQ | 2
R | 2m Ω 1W | CSSH0805FT2L00 | 1
C | 0.1uF 100V | GCJ188R72A104KA01D | 1
D |  | BAT41KFILM | 1
hbridgeC.SchDoc
Components | Value | Part number | Cantidad
MOSFET |  | TPN19008QM,LQ | 2
R | 2m Ω 1W | CSSH0805FT2L00 | 1
C | 0.1uF 100V | GCJ188R72A104KA01D | 1
D |  | BAT41KFILM | 1
gate_driver.SchDoc
Components | Value | Part number | Cantidad
Driver |  | DRV8323SRTAR | 1
C | 47nF 100V | C0603X473K1RACTU | 1
C | 1uF 25V | C1608X7R1E105K080AE | 1
C | 0.1uF 100V | GCJ188R72A104KA01D | 1
C | 1uF 6.3V | 08056C105MAT2A | 2
R | 2k Ω | AF0402JR-072KL | 2
R | 22 Ω | RC0603JR-0722RL | 3
C | 1000pF | 08056C102JAT2A | 3
bulk_capacitance.SchDoc
Components | Value | Part number | Cantidad
C | 47uF 100V | GRJ31CC72A475KE01K | 12
stm32g4.SchDoc
C | 0.1uF 6.3V | GRT033R60J104KE01J | 5
C | 1uF 6.3V | GRM188R60J105KA01D | 1
C | 4.7uF 6.3V | GRM035R60J475ME15D | 1
C | 10uF 6.3V | GRM155R60J106ME05D | 1
power_input.SchDoc
encoder.SchDoc
leds.SchDoc
external_port.SchDoc

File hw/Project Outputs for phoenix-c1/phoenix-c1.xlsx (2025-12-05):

Line # | Name | Description | Designator | Quantity | Manufacturer 1 | Manufacturer Part Number 1 | Manufacturer Lifecycle 1 | Supplier 1 | Supplier Part Number 1 | Supplier Unit Price 1 | Supplier Subtotal 1
 | STM32G431CBU6 | STMICROELECTRONICS - STM32G431CBU6 - MCU, 32BIT, 170MHZ, UFQFPN-48 | B1 | 1 | STMicroelectronics | STM32G431CBU6 | Volume Production | Mouser | 511-STM32G431CBU6 | 5.06 | 5.06
 | MAX15062AATA+T | Step-Down 60V, 300mA, Ultra-Small, High-Efficiency, Synchronous DC-DC Converters | B2 | 1 | Analog Devices | MAX15062AATA+T | Volume Production | Mouser | 700-MAX15062AATA+T | 2.33 | 2.33
 | DRV8323SRTAR | Gate Drivers 60V Three-Phase Smart Gate Driver With Three Current Shunt Amplifiers 40-WQFN -40 to 125 | B3 | 1 | Texas Instruments | DRV8323SRTAR | Volume Production | Mouser | 595-DRV8323SRTAR | 3.57 | 3.57
 | AS5600-ASOM | IC SENSOR MAG ROTARY 12BIT 8SOIC | B4 | 1 | Osram | AS5600-ASOM | Volume Production | Mouser | 985-AS5600-ASOM | 3 | 3
 | 10µF | Ceramic Capacitor, Ceramic, 6.3V, 20% +Tol, 20% -Tol, X5R, 15% TC, 10uF, Surface Mount, 0402 | C1, C11 | 2 | Murata | GRM155R60J106ME05D | Volume Production | Mouser | 81-GRM155R60J106M05D | 0.1 | 0.2
 | 4.7µF | Ceramic Capacitor, Ceramic, 6.3V, 20% +Tol, 20% -Tol, X5R, 15% TC, 4.7uF, Surface Mount, 0201 | C2 | 1 | Murata | GRM035R60J475ME15D | Volume Production | Mouser | 81-GRM035R60J475ME5D | 0.1 | 0.1
 | 100nF | Ceramic Capacitor, Multilayer, Ceramic, 6.3V, 10% +Tol, 10% -Tol, X5R, 15% TC, 0.1uF, Surface Mount, 0201 | C3, C5, C6, C7, C8, C35 | 6 | Murata | GRT033R60J104KE01J | Volume Production | Mouser | 81-GRT033R60J104KE1J | 0.017 | 0.17
 | 1µF | Ceramic Capacitor, Ceramic, 6.3V, 10% +Tol, 10% -Tol, X5R, 15% TC, 1uF, Surface Mount, 0603 | C4 | 1 | Murata | GRM188R60J105KA01D | Not Recommended for New Design | Mouser | 81-GRM39R105K6.3 | 0.14 | 0.14
 | 1µF | Ceramic Capacitor, Ceramic, 100V, 10% +Tol, 10% -Tol, X7S, 22% TC, 1uF, Surface Mount, 0805 | C9, C10 | 2 | Murata | GCM21BC72A105KE36L | Volume Production | Mouser | 81-GCM21BC72A105KE6L | 0.42 | 0.84
 | 4.7µF | Ceramic Capacitor, Multilayer, Ceramic, 100V, 10% +Tol, 10% -Tol, X7S, 22% TC, 4.7uF, Surface Mount, 1206 | C14, C15, C16, C17, C18, C19, C20, C21, C22, C23, C37 | 11 | Murata | GRJ31CC72A475KE01K | Volume Production | Mouser | 81-GRJ31CC72A475KE1K | 0.387 | 4.26
 | 100nF | Cap Ceramic 0.1uF 100V X7R 10% Pad SMD 0603 Soft Termination 125C Automotive T/R | C24, C25, C26, C28 | 4 | Murata | GCJ188R72A104KA01D | Volume Production | Mouser | 81-GCJ188R72A104KA1D | 0.16 | 0.64
 | 1µF | 25V 1uF X7R 卤10% 0603 Multilayer Ceramic Capacitors MLCC - SMD/SMT ROHS | C27 | 1 | TDK | C1608X7R1E105K080AE | Volume Production | Mouser | 810-C1608X7R1E105KAE | 0.24 | 0.24
 | 47nF | Multilayer Ceramic Capacitors MLCC - SMD/SMT 100V 0.047uF X7R 0603 10% Flex Soft | C29 | 1 | KEMET | C0603X473K1RACTU | Volume Production | Mouser | 80-C0603X473K1R | 0.44 | 0.44
 | 1nF | Multilayer Ceramic Capacitors MLCC - SMD/SMT 6.3V 1000pF X7R 0805 5% | C30, C32, C33 | 3 | KYOCERA AVX | 08056C102JAT2A | Unknown | Mouser | 581-08056C102JAT2A | 0.26 | 0.78
 | 1uF | Multilayer Ceramic Capacitors MLCC - SMD/SMT 6.3V 1uF X7R 0805 20% | C31, C34 | 2 | KYOCERA AVX | 08056C105MAT2A | Unknown | Mouser | 581-08056C105MAT2A | 0.34 | 0.68
 | APT1608SURCK | APT1608SURCK Red Led, 630 Nm 1608 (0603) Clear, Rectangle Lens SMD Package | D1, D2 | 2 | Kingbright | APT1608SURCK | Volume Production | Mouser | 604-APT1608SURCK | 0.2 | 0.4
 | SMBJ48D-M3/I | Trans Voltage Suppressor Diode, 600W, 48V V(RWM), Unidirectional, 1 Element, Silicon, DO-214AA | D3 | 1 | Vishay | SMBJ48D-M3/I | Volume Production | Mouser | 78-SMBJ48D-M3I | 0.34 | 0.34
 | BAT41KFILM | Low Capacitance Small Signal 200 mA 1 V Schottky Diode Surface Mount - SOD-523 | D4, D5, D6 | 3 | STMicroelectronics | BAT41KFILM | Volume Production | Mouser | 511-BAT41KFILM | 0.34 | 1.02
 | S6B-ZR-SM4A-TF(LF)(SN) | CONN HEADER SMD R/A 6POS 1.5MM | J1, J2 | 2 | JST | S6B-ZR-SM4A-TF(LF)(SN) | Volume Production | Mouser | 306-S6BZRSM4ATFLFSN | 0.65 | 1.3
 | XT30PW-M | 30A Low Temperature Rise Fire Retardant Plug | J3 | 1
 | TH_UART |  | J4 | 1
 | JUMPER |  | JU1 | 1
 | B82464P4333M000 | General Purpose Inductor, 33uH, 20%, 1 Element, Ferrite-Core, SMD, 1515 | L1 | 1 | Coilcraft | LPS4018-333MRC | Volume Production | Mouser | 994-LPS4018-333MRC | 1.46 | 1.46
 | TPN19008QM,LQ | Power MOSFET, N Channel, 80 V, 38 A, 0.0147 ohm, TSON, Surface Mount | Q1, Q2, Q3, Q4, Q5, Q6 | 6 | Toshiba | TPN19008QM,LQ | Volume Production | Mouser | 757-TPN19008QM,LQ | 1.11 | 6.66
 | 560Ω | Res Thin Film 0603 560 Ohm 0.1% 0.1W(1/10W) ±25ppm/C Pad SMD T/R | R1, R2 | 2 | Yageo Group | RT0603BRD07560RL | Volume Production | Mouser | 603-RT0603BRD07560RL | 0.1 | 0.2
 | 2mΩ | Res Metal Alloy 0805 0.002 Ohm 1% 1W ±75ppm/C Pad SMD T/R Automotive AEC-Q200 | R3, R4, R5 | 3 | Stackpole Electronics | CSSH0805FT2L00 | Volume Production | Mouser | 708-CSSH0805FT2L00 | 0.6 | 1.8
 | 22Ω | 100Mw Thick Film Resistors 100Ppm/ 5% 22 0603 Chip Resistor Surface Mount Rohs | R6, R7, R9 | 3 | Yageo Group | RC0603JR-0722RL | Volume Production | Mouser | 603-RC0603JR-0722RL | 0.005 | 0.05
 | 2kΩ | Anti-Sulfurated Chip Resistor Thick Film 0402 2kOhm 5% Paper T/R | R8, R10, R11, R12 | 4 | Yageo Group | AF0402JR-072KL | Volume Production | Mouser | 603-AF0402JR-072KL | 0.007 | 0.07
 | Motor Conector | Generic connector, single row | X1, X2, X3, X4, X5 | 5

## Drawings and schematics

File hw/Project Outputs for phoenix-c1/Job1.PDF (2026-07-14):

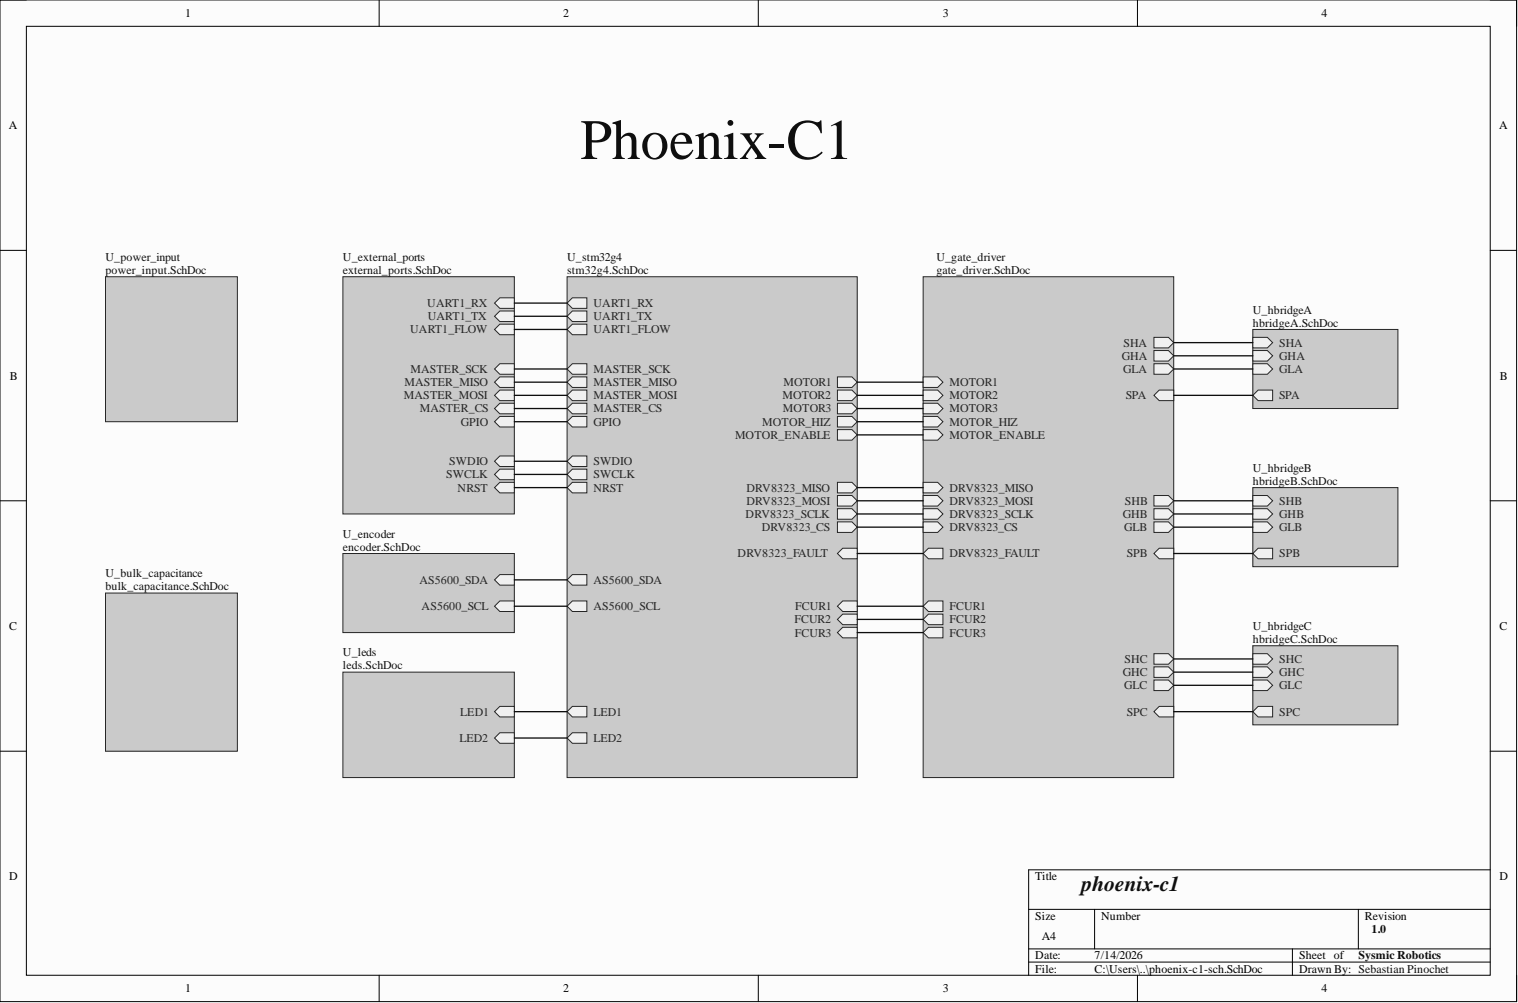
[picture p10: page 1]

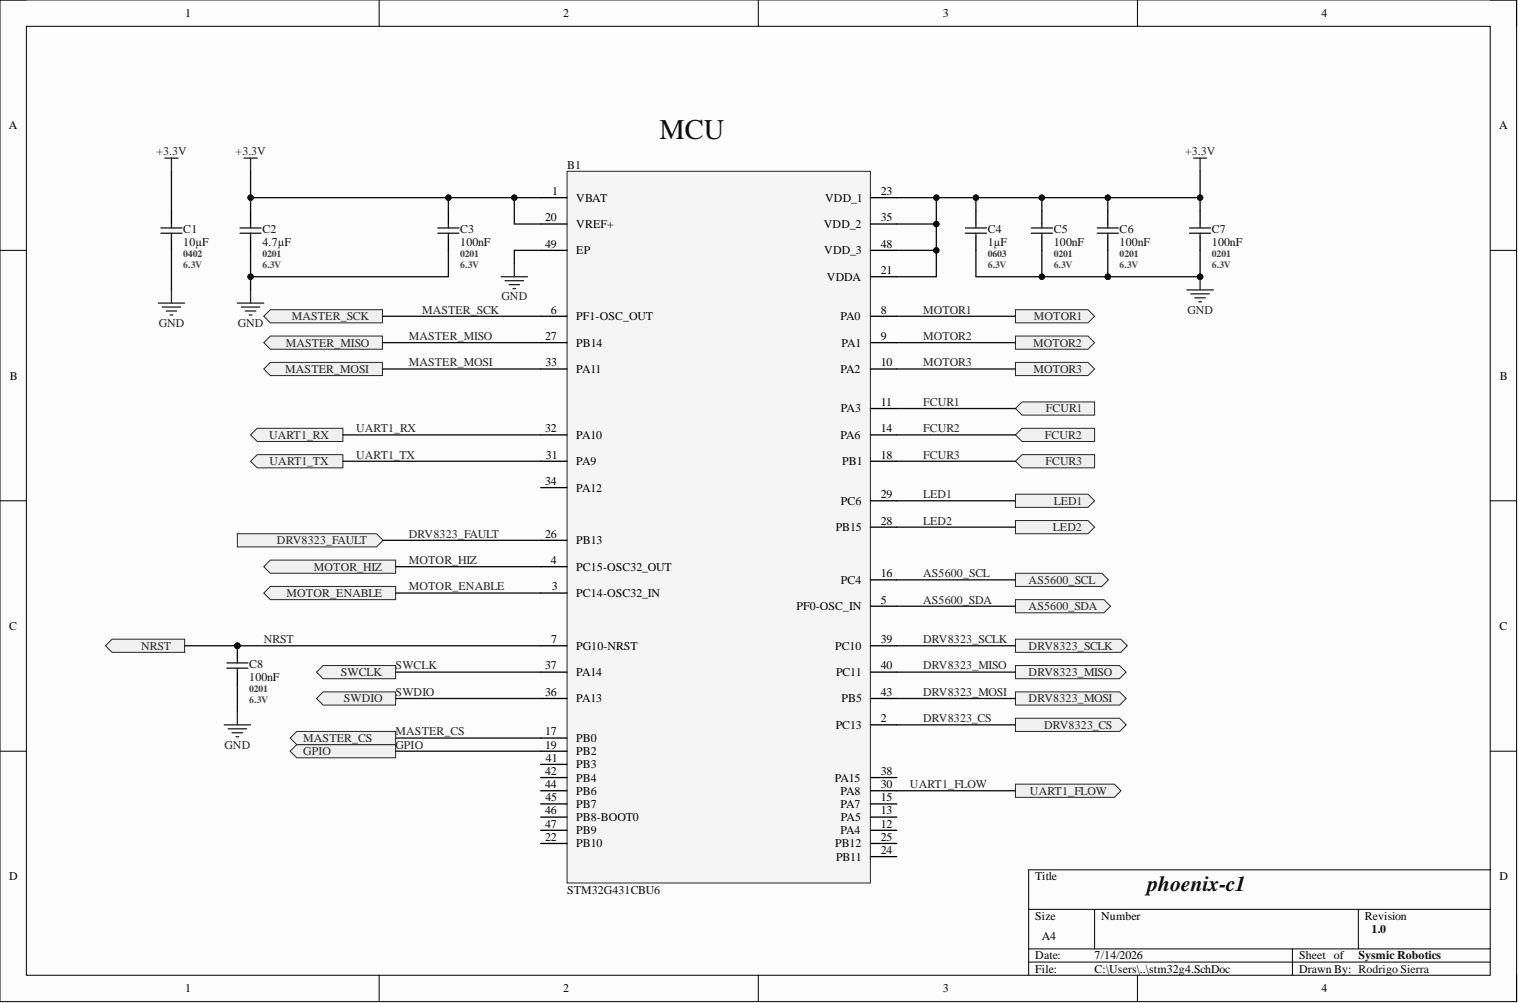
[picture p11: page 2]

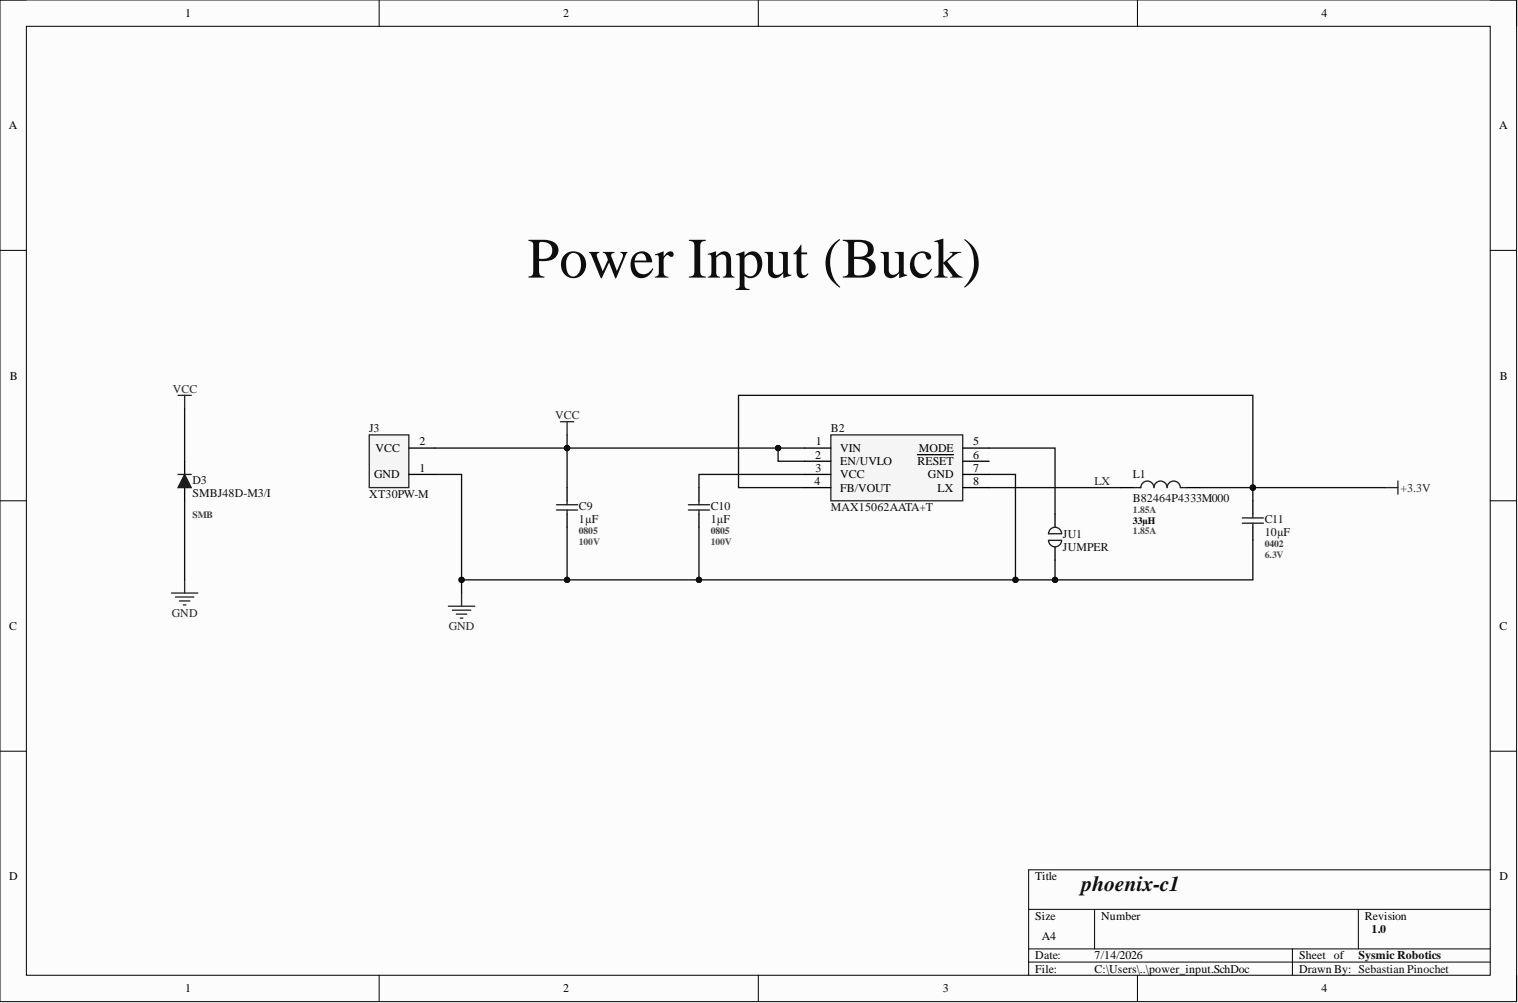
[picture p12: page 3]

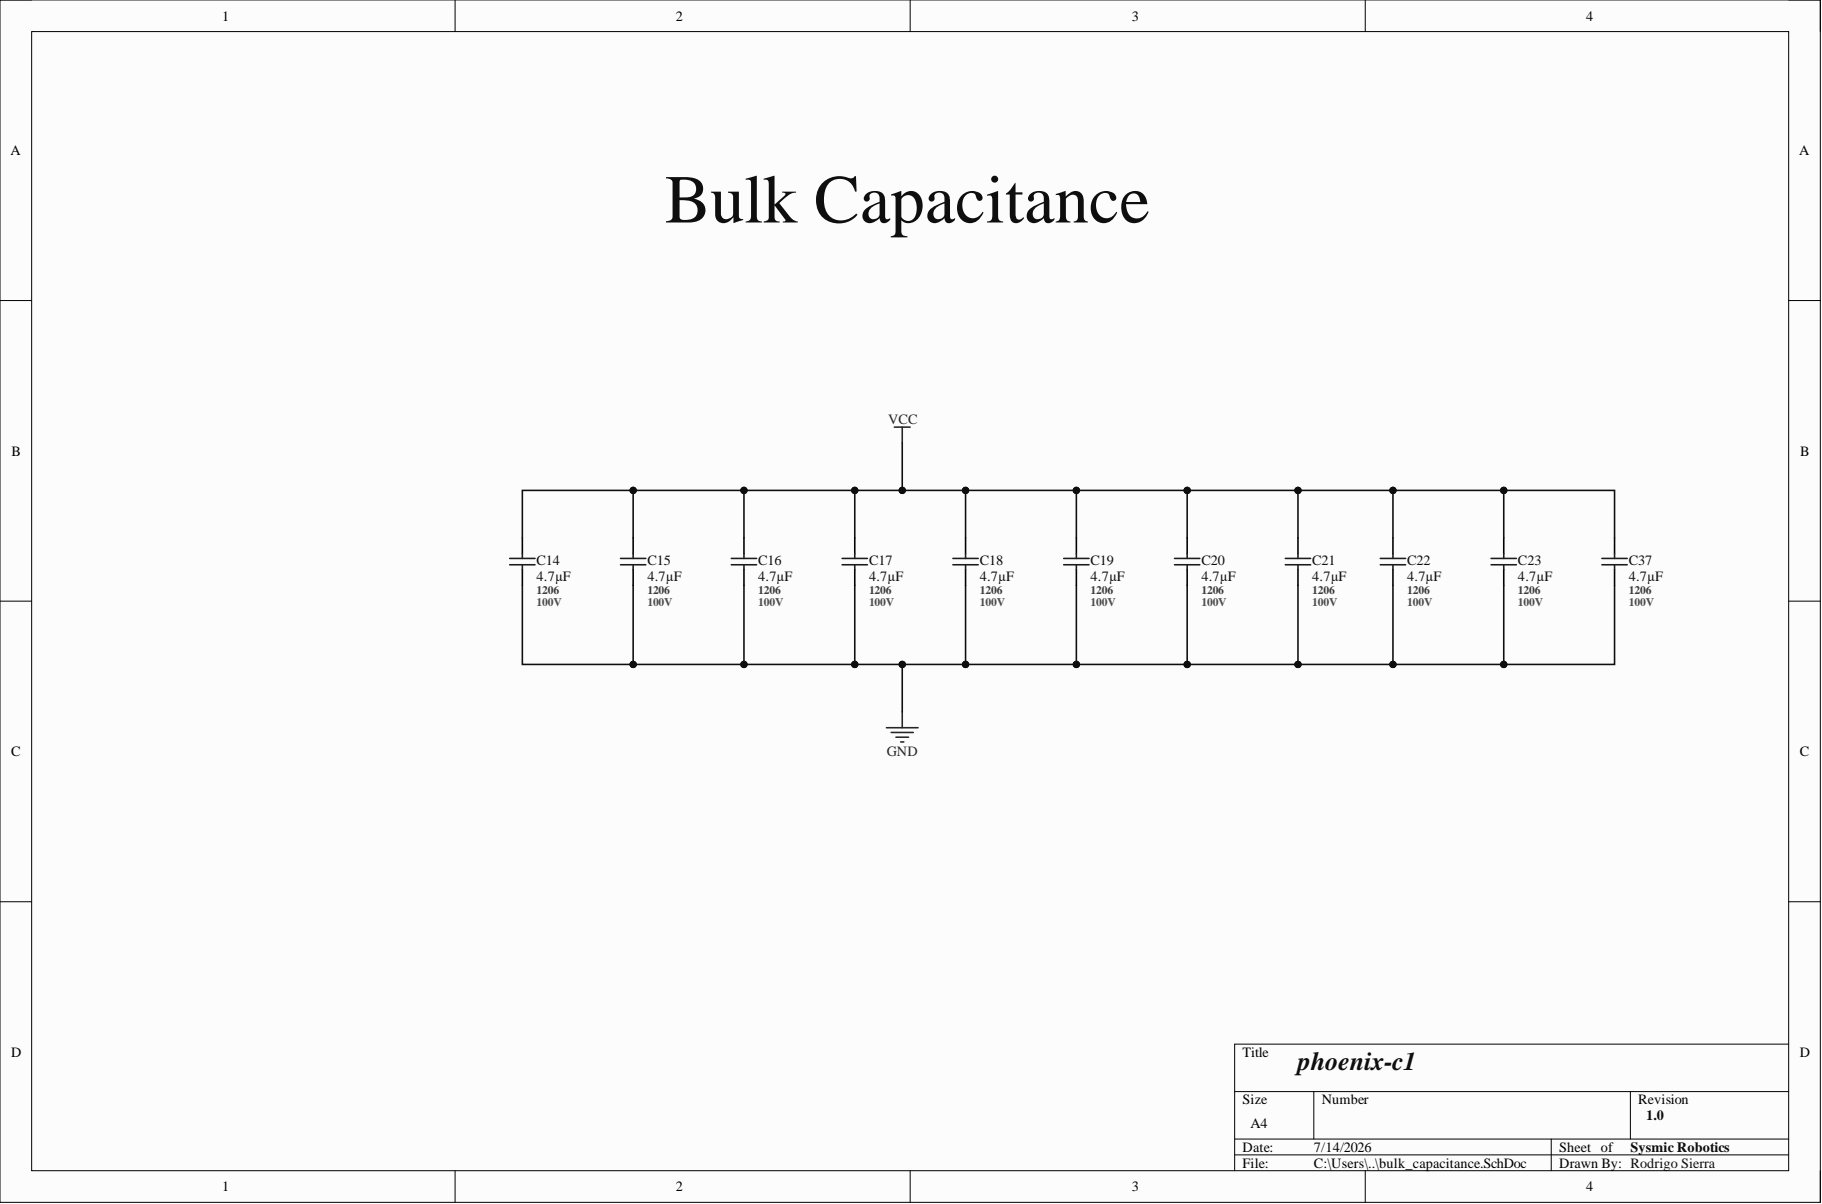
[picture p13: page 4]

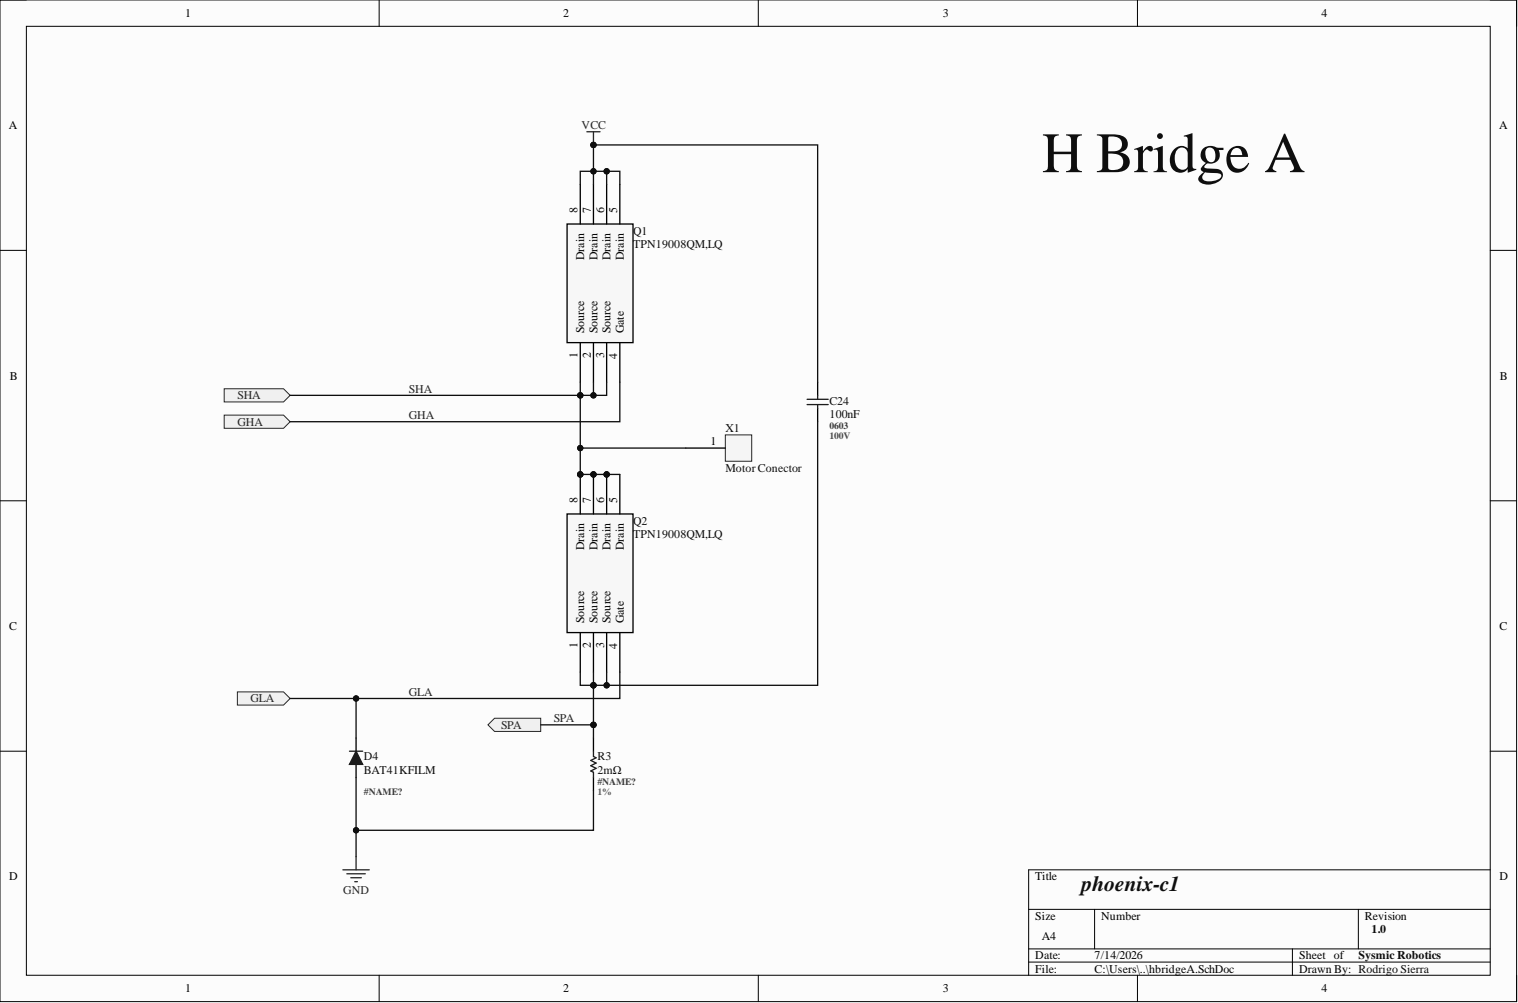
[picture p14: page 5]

Gate 4 Drain 5 Drain 6 Drain 7 Drain 8

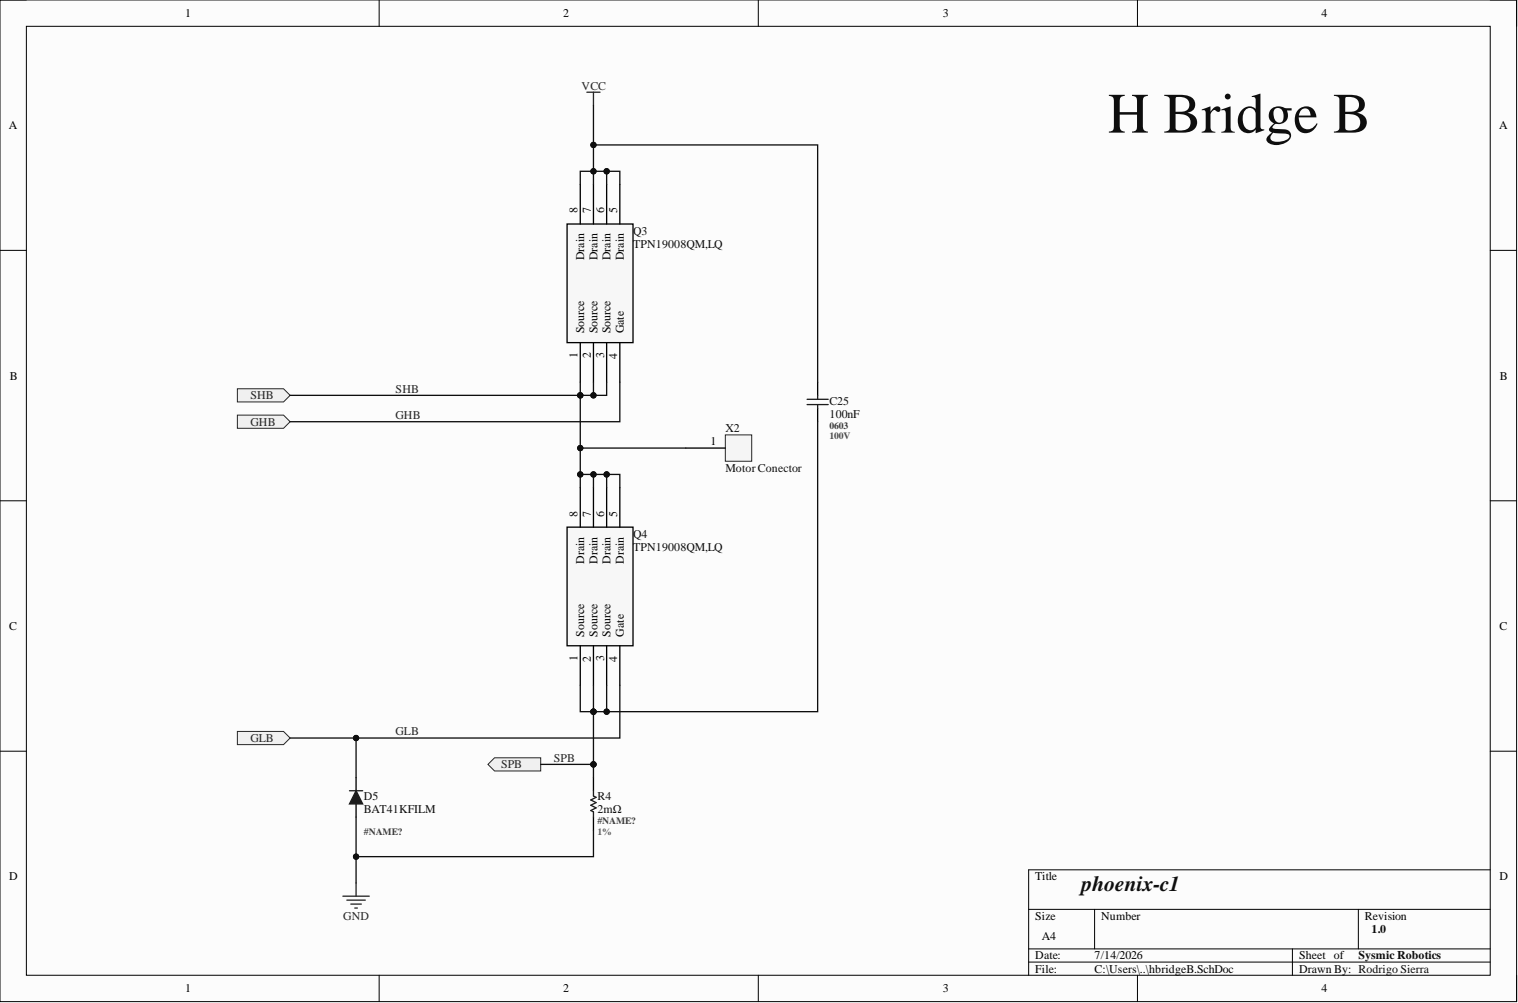
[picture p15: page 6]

Gate 4 Drain 5 Drain 6 Drain 7 Drain 8

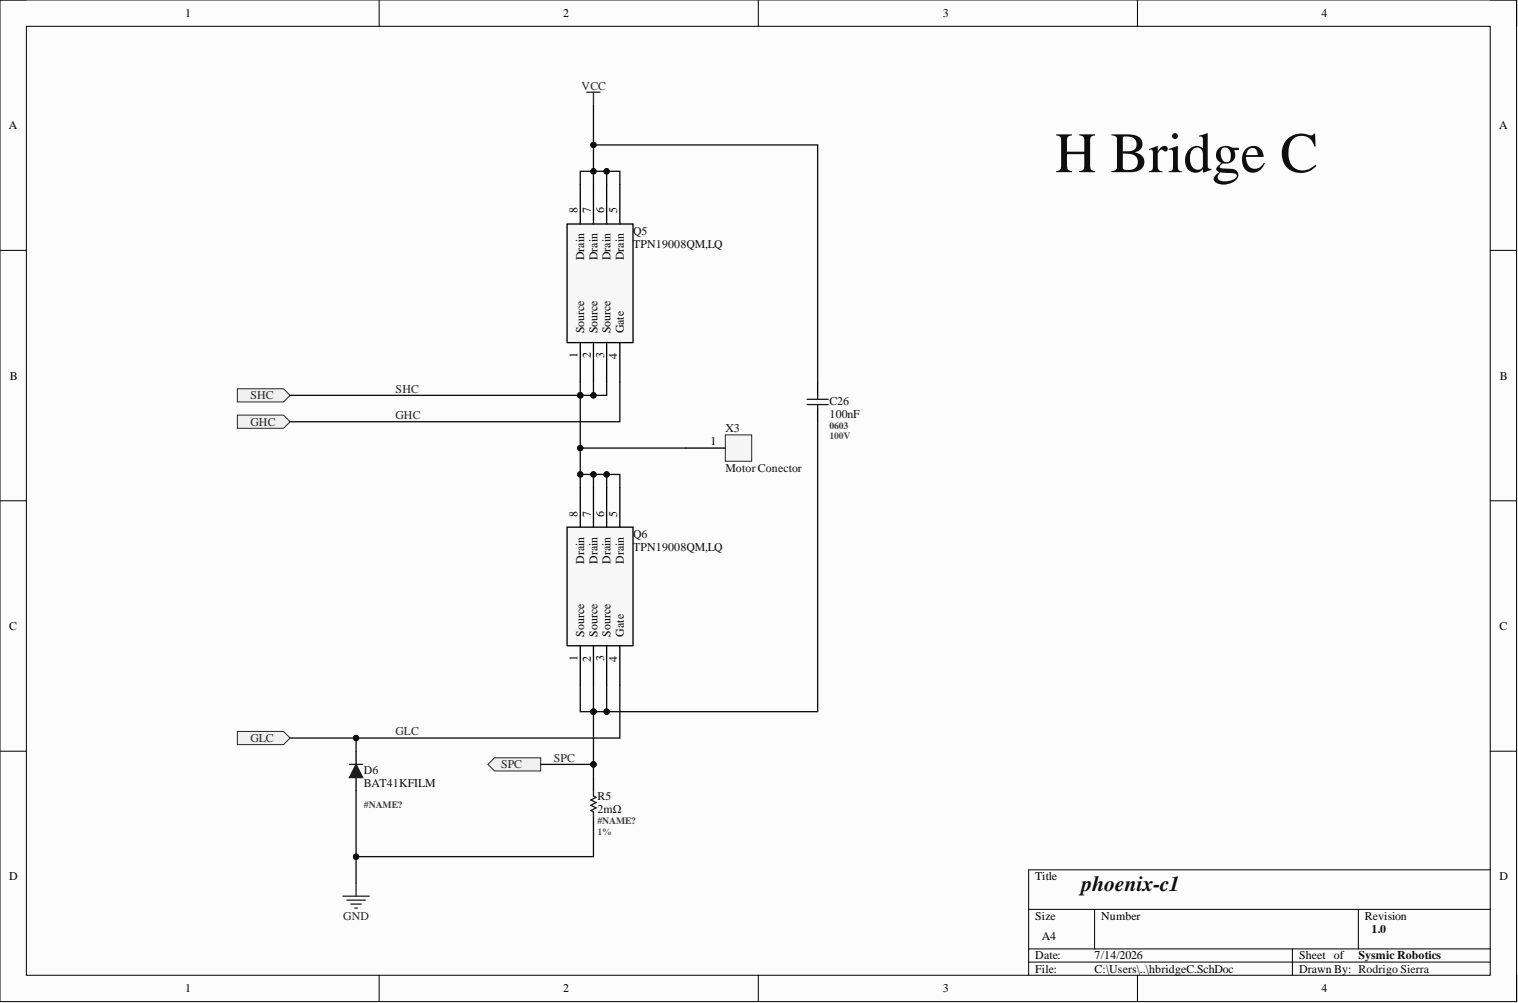
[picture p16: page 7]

Gate 4 Drain 5 Drain 6 Drain 7 Drain 8

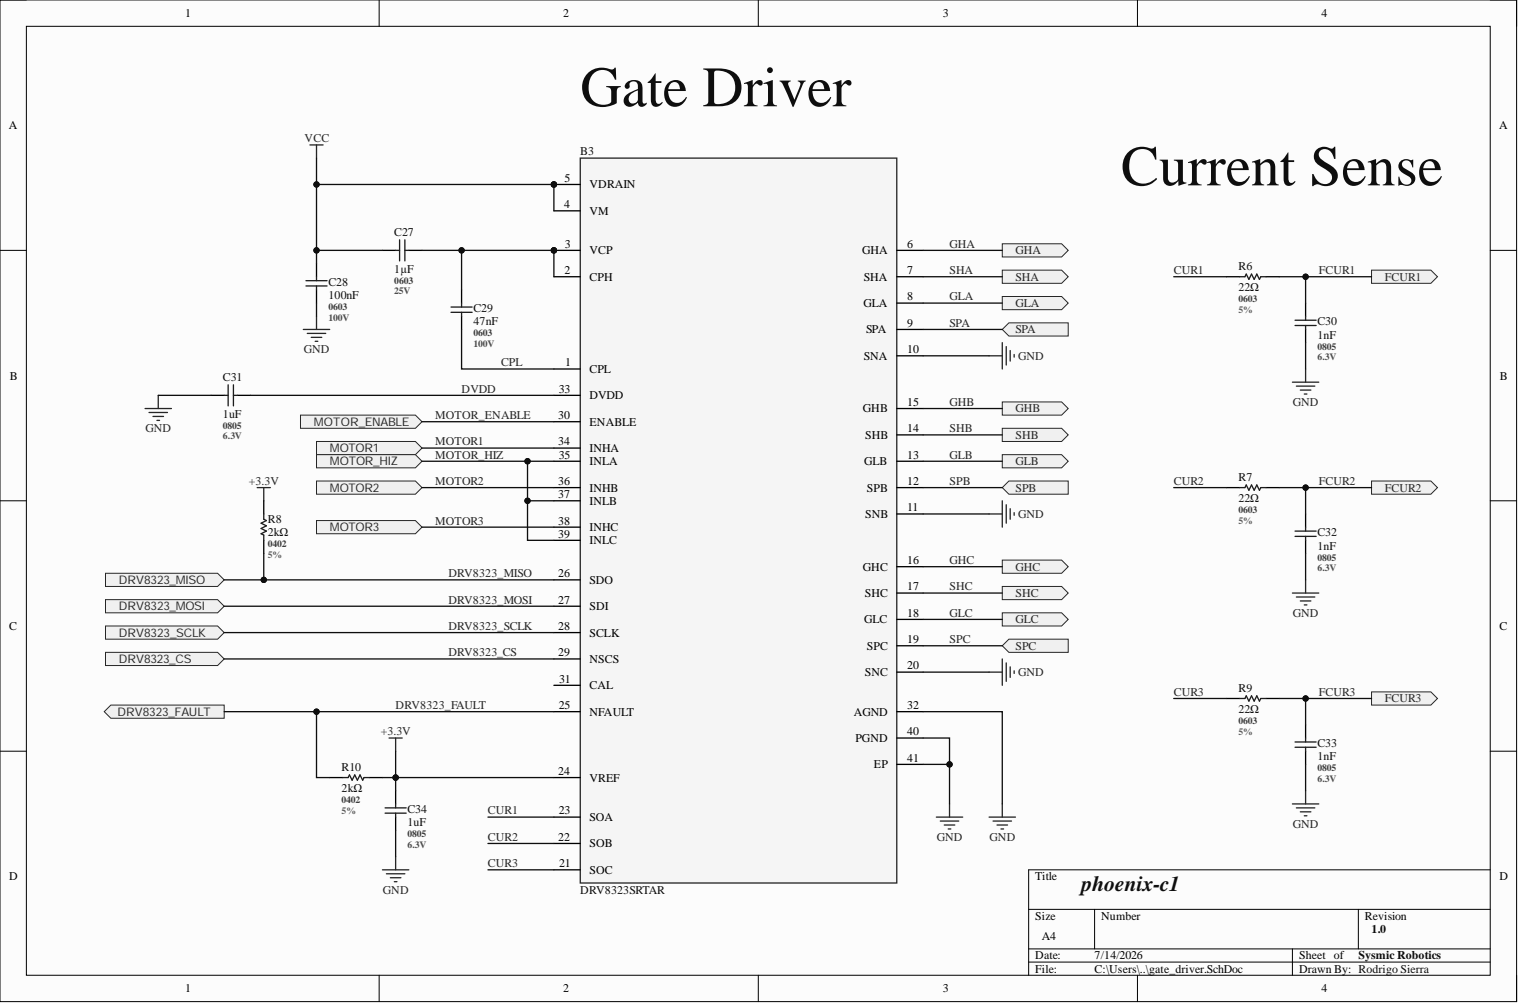
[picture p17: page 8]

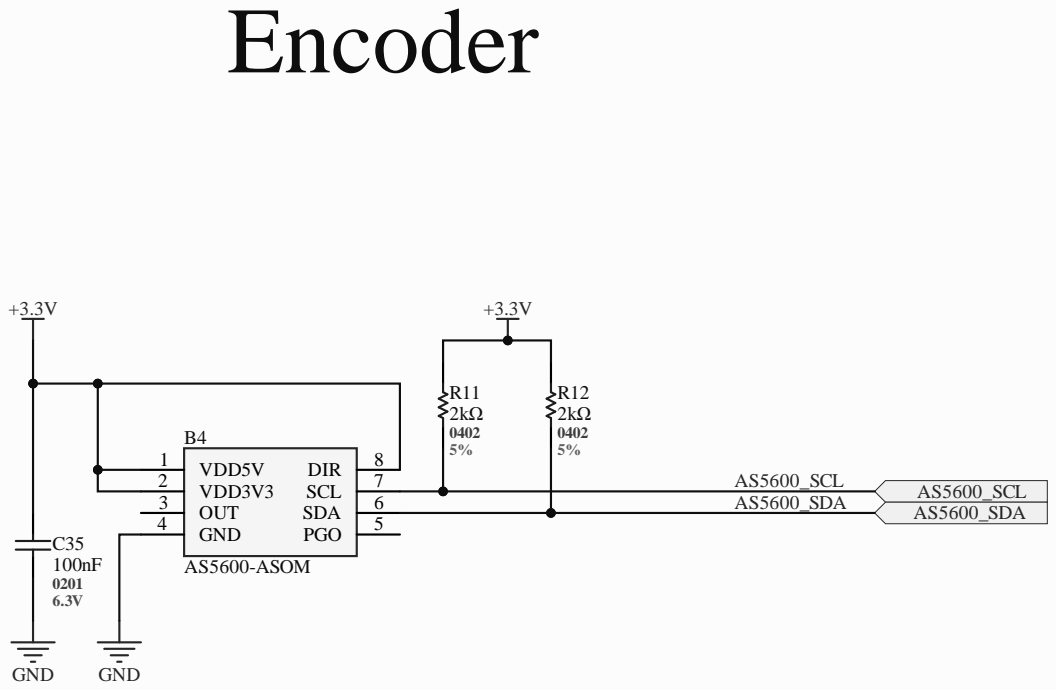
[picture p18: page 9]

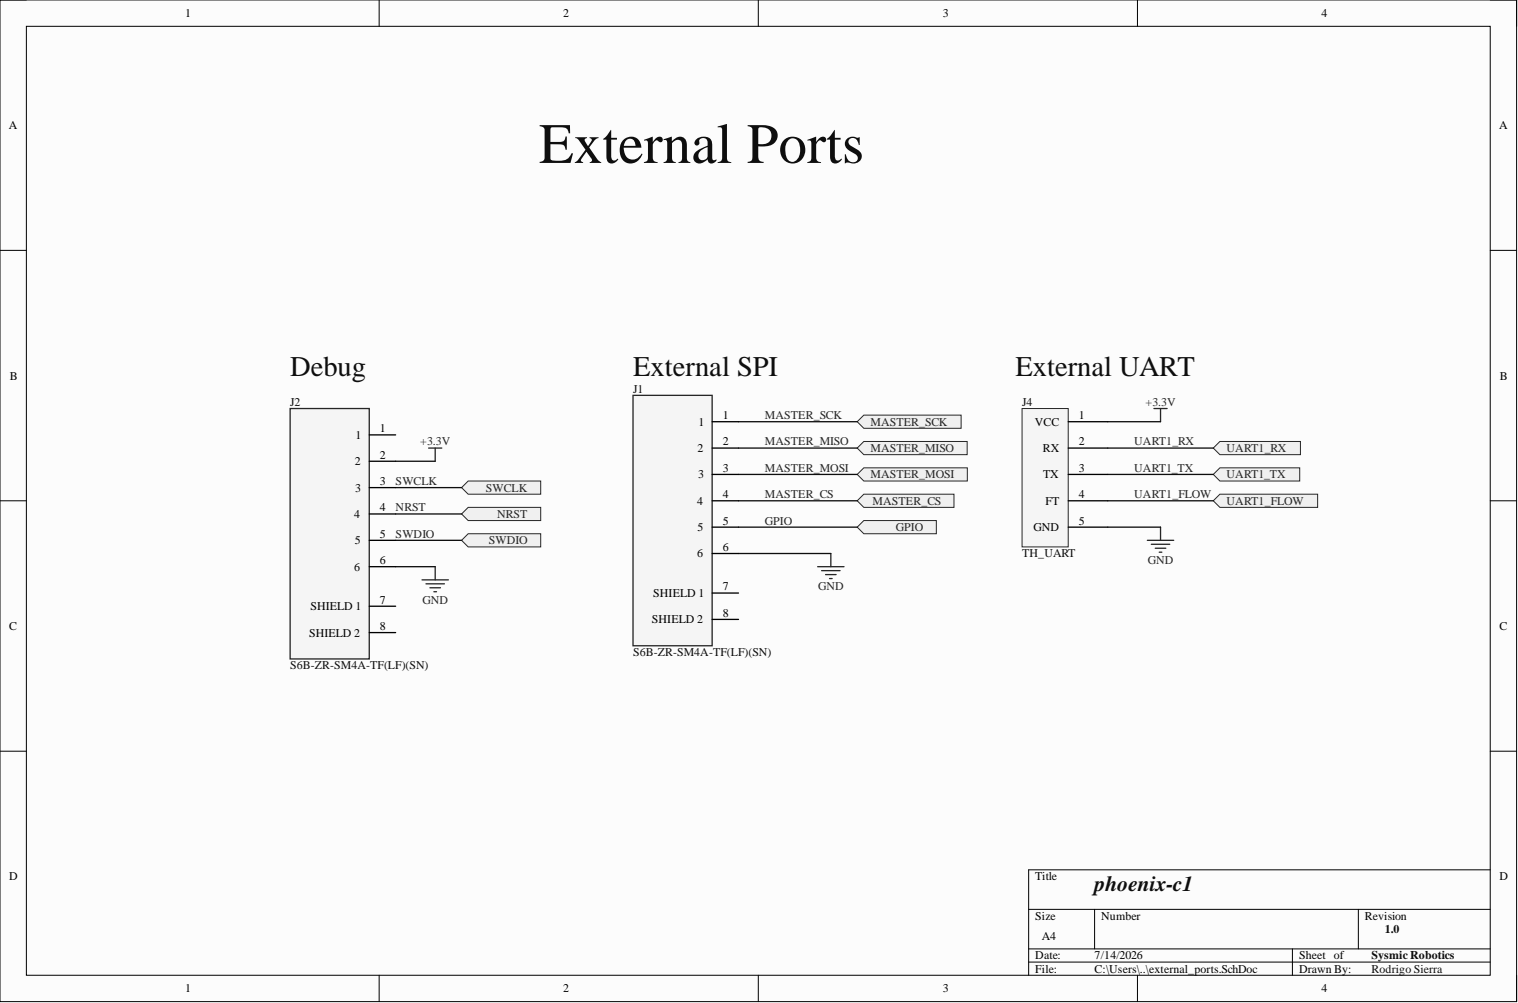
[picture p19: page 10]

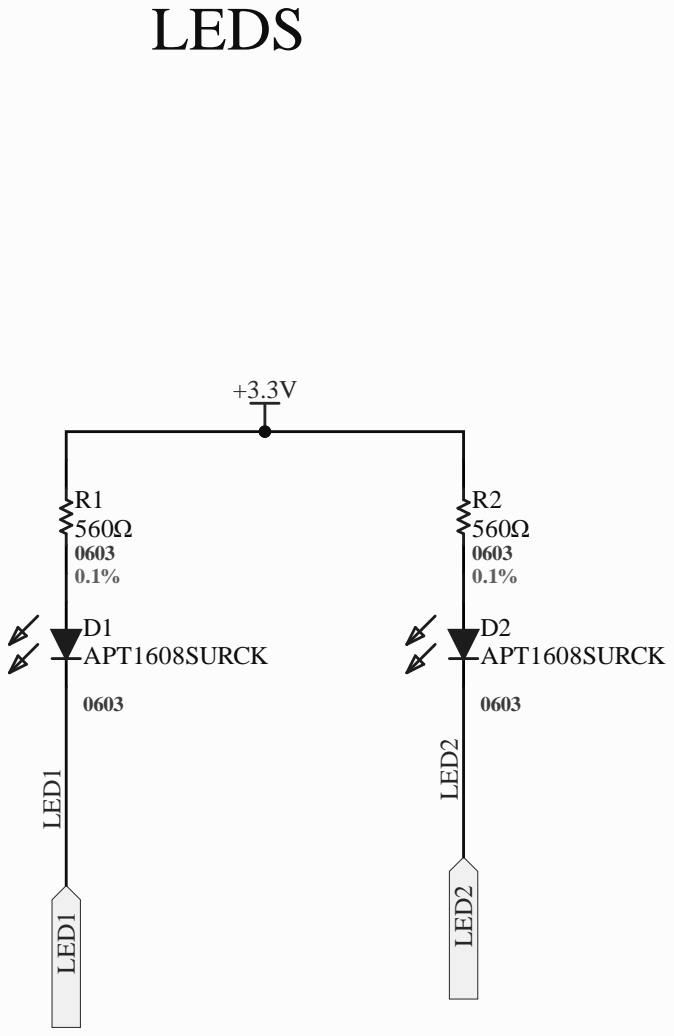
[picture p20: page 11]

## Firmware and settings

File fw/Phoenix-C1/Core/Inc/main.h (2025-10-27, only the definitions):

#define MOTOR_ENABLE_Pin GPIO_PIN_14
#define MOTOR_ENABLE_GPIO_Port GPIOC
#define MOTOR_HIZ_Pin GPIO_PIN_15
#define MOTOR_HIZ_GPIO_Port GPIOC
#define MOTOR_1_Pin GPIO_PIN_0
#define MOTOR_1_GPIO_Port GPIOA
#define MOTOR_2_Pin GPIO_PIN_1
#define MOTOR_2_GPIO_Port GPIOA
#define MOTOR_3_Pin GPIO_PIN_2
#define MOTOR_3_GPIO_Port GPIOA
#define nFAULT_Pin GPIO_PIN_13
#define nFAULT_GPIO_Port GPIOB
#define LED1_Pin GPIO_PIN_15
#define LED1_GPIO_Port GPIOB
#define LED2_Pin GPIO_PIN_6
#define LED2_GPIO_Port GPIOC

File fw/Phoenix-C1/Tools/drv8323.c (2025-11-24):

#include "drv8323.h"

#include <string.h>

// ----------------------------------------------
// DRV8323 SPI framing
// 16-bit frame: [15]=R/W (1=read,0=write), [14:11]=addr, [10:0]=data
// Big-endian transfer: MSB first
// ----------------------------------------------
#define DRV8323_SPI_RW_READ        (0x8000u)
#define DRV8323_SPI_ADDR_SHIFT     (11u)
#define DRV8323_SPI_ADDR_MASK      (0x0Fu)
#define DRV8323_SPI_DATA_MASK      (0x07FFu)

// ----------------------------------------------
// Selected register field helpers (verify with datasheet for your build)
// These symbolic values aim to be reasonable defaults; adjust to your design.
// ----------------------------------------------
// DRV_CTRL (0x02)
#define DRV8323_DRVCTRL_CLR_FLT    (1u << 0)  // Clear faults latch when written as 1
// Optional feature bits (datasheet specific):
#define DRV8323_DRVCTRL_DIS_GDF    (1u << 1)  // Disable gate driver fault (example)
#define DRV8323_DRVCTRL_OTW_REP    (1u << 2)  // Report OTW (example)
// PWM mode bits example (3x PWM). Check datasheet PWM_MODE field position.
#define DRV8323_DRVCTRL_PWM_MODE_3 (0x2u << 5)

// GATE_DRV_HS (0x03), GATE_DRV_LS (0x04) fields are device-specific.
// Provide moderate drive strengths and TDRIVE = 500ns as safe defaults.
#define DRV8323_IDRIVEP_50mA       (0x5u)     // example code
#define DRV8323_IDRIVEN_100mA      (0x6u)     // example code
#define DRV8323_TDRIVE_500ns       (0x2u)     // example code

// OCP_CTRL (0x05): Set overcurrent to a moderate threshold, latch shutdown.
#define DRV8323_OCP_DEG_4us        (0x1u)     // example code
#define DRV8323_OCP_MODE_LATCH     (0x2u)     // example code
#define DRV8323_VDS_LVL_MID        (0x6u)     // example mid-level VDS threshold

// CSA_CTRL (0x06): Set CSA gain and reference to a common value (20 V/V, 0.25V)
#define DRV8323_CSA_GAIN_20V       (0x2u)     // example code
#define DRV8323_CSA_FET_LOW_SIDE   (0x0u)     // example code
#define DRV8323_CSA_VREF_0V25      (0x0u)     // example code (depends on VREF selection)
#define DRV8323_CSA_CAL_CH1_OFF    (0x0u)     // example code

// Convenience timeout for SPI transactions (ms)
#ifndef DRV8323_SPI_TIMEOUT_MS
#define DRV8323_SPI_TIMEOUT_MS     10u
#endif

// ----------------------------------------------
// Internal helpers
// ----------------------------------------------
static inline float drv8323_clampf(float x, float lo, float hi)
{
	if (x < lo) return lo;
	if (x > hi) return hi;
	return x;
}

static uint32_t drv8323_get_tim_arr(TIM_HandleTypeDef *htim)
{
#if defined(__HAL_TIM_GET_AUTORELOAD)
	return __HAL_TIM_GET_AUTORELOAD(htim);
#else
	return htim->Init.Period;
#endif
}

// Perform a single 16-bit SPI transaction.
// Assumes hardware NSS managed by SPI peripheral.
static HAL_StatusTypeDef drv8323_spi_transfer(drv8323_t *drv, uint16_t tx, uint16_t *rx)
{
	if (drv == NULL || drv->hspi == NULL) {
		return HAL_ERROR;
	}

	uint8_t txb[2];
	uint8_t rxb[2] = {0, 0};
	txb[0] = (uint8_t)((tx >> 8) & 0xFF);
	txb[1] = (uint8_t)(tx & 0xFF);

	HAL_StatusTypeDef st = HAL_SPI_TransmitReceive(drv->hspi, txb, rxb, 2, DRV8323_SPI_TIMEOUT_MS);
	if (st != HAL_OK) {
		return st;
	}
	if (rx) {
		*rx = ((uint16_t)rxb[0] << 8) | (uint16_t)rxb[1];
	}
	return HAL_OK;
}

HAL_StatusTypeDef drv8323_write_reg(drv8323_t *drv, uint8_t addr, uint16_t value)
{
	uint16_t frame = ((uint16_t)(addr & DRV8323_SPI_ADDR_MASK) << DRV8323_SPI_ADDR_SHIFT)
				   | (value & DRV8323_SPI_DATA_MASK);
	return drv8323_spi_transfer(drv, frame, NULL);
}

HAL_StatusTypeDef drv8323_read_reg(drv8323_t *drv, uint8_t addr, uint16_t *value)
{
	uint16_t rx = 0;
	uint16_t frame = DRV8323_SPI_RW_READ
				   | ((uint16_t)(addr & DRV8323_SPI_ADDR_MASK) << DRV8323_SPI_ADDR_SHIFT);
	HAL_StatusTypeDef st = drv8323_spi_transfer(drv, frame, &rx);
	if (st != HAL_OK) return st;
	if (value) {
		*value = (rx & DRV8323_SPI_DATA_MASK);
	}
	return HAL_OK;
}

// ----------------------------------------------
// Public API implementation
// ----------------------------------------------
void drv8323_init(drv8323_t *drv,
				  SPI_HandleTypeDef *hspi,
				  GPIO_TypeDef *enable_port, uint16_t enable_pin,
				  GPIO_TypeDef *hiz_port,    uint16_t hiz_pin,
				  GPIO_TypeDef *fault_port,  uint16_t fault_pin,
				  TIM_HandleTypeDef *htim_pwm,
				  uint32_t tim_channel_u,
				  uint32_t tim_channel_v,
				  uint32_t tim_channel_w)
{
	if (!drv) return;

	memset(drv, 0, sizeof(*drv));
	drv->hspi = hspi;
	drv->enable_port = enable_port;
	drv->enable_pin = enable_pin;
	drv->hiz_port = hiz_port;
	drv->hiz_pin = hiz_pin;
	drv->fault_port = fault_port;
	drv->fault_pin = fault_pin;
	drv->htim_pwm = htim_pwm;
	drv->tim_channel_u = tim_channel_u;
	drv->tim_channel_v = tim_channel_v;
	drv->tim_channel_w = tim_channel_w;

	// Safe startup state
	drv->duty_u = 0.0f;
	drv->duty_v = 0.0f;
	drv->duty_w = 0.0f;

	// Keep driver asleep
	if (drv->enable_port) {
		HAL_GPIO_WritePin(drv->enable_port, drv->enable_pin, GPIO_PIN_RESET);
	}
	// Put inverter in Hi-Z (coast)
	if (drv->hiz_port) {
		// hiz=true => MOTOR_HIZ low (per project wiring: 0 => Hi-Z)
		HAL_GPIO_WritePin(drv->hiz_port, drv->hiz_pin, GPIO_PIN_RESET);
	}

	drv->initialized = true;
}

HAL_StatusTypeDef drv8323_clear_faults(drv8323_t *drv)
{
	if (!drv) return HAL_ERROR;

	// Try CLR_FLT write pulse
	HAL_StatusTypeDef st = drv8323_write_reg(drv, DRV8323_REG_DRV_CTRL, DRV8323_DRVCTRL_CLR_FLT);
	if (st != HAL_OK) return st;
	// Optionally clear back to 0 to avoid holding the bit
	st = drv8323_write_reg(drv, DRV8323_REG_DRV_CTRL, 0u);
	if (st != HAL_OK) return st;

	// If external nFAULT is still low, fallback: brief nSLEEP cycle
	if (drv->fault_port) {
		GPIO_PinState s = HAL_GPIO_ReadPin(drv->fault_port, drv->fault_pin);
		if (s == GPIO_PIN_RESET) {
			if (drv->enable_port) {
				HAL_GPIO_WritePin(drv->enable_port, drv->enable_pin, GPIO_PIN_RESET);
				HAL_Delay(2);
				HAL_GPIO_WritePin(drv->enable_port, drv->enable_pin, GPIO_PIN_SET);
				HAL_Delay(2);
			}
		}
	}
	return HAL_OK;
}
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

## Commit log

2025-10-23 feat(Altium): finalize schematics, footprints, and 3D models
    - Completed PMSM FOC driver schematics (power, control, sensing)
    - Linked custom footprints to validated STEP models; ERC/DRC clean
    [Sheet1.SchDoc, phoenix-c1-pcblib1.PcbLib, phoenix-c1-schlib.SchLib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]
2025-10-23 fix(Altium): sensor 3D model
    -STEP model for MAX15062AATAT
    [phoenix-c1-pcblib1.PcbLib]
2025-10-26 refactor(repo): restructure folders for clearer hw/fw separation
    [Sheet1.SchDoc, phoenix-c1-pcblib1.PcbLib, phoenix-c1-sch.SchDoc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]
2025-10-27 feat(schematic): schematics for modules added
    Schematics for stm32g4, Hbridges, bulk capacitance, power input, and ports
    [bulk_capacitance.SchDoc, hbridgeA.SchDoc, hbridgeB.SchDoc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]
2025-10-27 docs(project)
    excel with pasive componentes added WIP
    [Libro1.xlsx]
2025-10-27 docs(project): document and restructure with docs
    docs carpet was add for documents such as excels, design doc, and specification doc.
    [passive components.xlsx, stm32_pin_config.xlsx]
2025-10-27 feat(fw): first firmware with .ioc config
    CubeIDE project was add including pin config from excel in fw carpet
    [hbridgeA.SchDoc, passive components.xlsx, phoenix-c1-pcblib1.PcbLib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]
2025-10-27 fix(hw): passive components for H bridge was add WIP
    realized MOSFET is the incorrect, that ought to change it (WIP)
    [hbridgeA.SchDoc]
2025-10-28 docs(Passive Components)
    excel file DONE that lists passive components
    with estimated USD and CLP prices.
    [passive components.xlsx]
2025-10-28 docs(rev1 - Passive components)
    primera revision de documento de elementos pasivos, se deja en "x" componentes que faltan revisar y acrualizar link de MOUSER
    [passive components.xlsx]
2025-10-28 feat(schematic): schematic for MOSFET was updated WIP
    MOSFET was change and first version of schematic for h bridge was make.
    [hbridgeA.SchDoc, hbridgeB.SchDoc, hbridgeC.SchDoc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]
2025-10-29 docs(rev2: passive components)
    second revition of passive componentes, this time every componente with 1608 [METRIC] and link mouser
    [passive components.xlsx]
2025-10-29 feat(schematic): gate driver and passive component schematics was added
    new pasives component form excel was add to altium and it was add schematic for the gate driver
    [gate_driver.SchDoc, hbridgeA.SchDoc, hbridgeB.SchDoc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]
2025-10-30 feat(schematics): schematic for bulk capacitance was finished
    More passive components has been add. it was added component for LED sense and Datasheet for components was added too.
    [bulk_capacitance.SchDoc, encoder.SchDoc, gate_driver.SchDoc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]
2025-11-02 feat(schematic): schematic for smt32g4 was finished
    More passive components was added to the excel and altium and .BomDom was created
    [bulk_capacitance.SchDoc, gate_driver.SchDoc, hbridgeA.SchDoc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]
2025-11-03 docs(excel): Footprint checker was added to excel
    [gate_driver.SchDoc, passive components.xlsx, phoenix-c1-schlib.SchLib]
2025-11-03 fix(schematics): schematic +V and GND was changed WIP
    [bulk_capacitance.SchDoc, gate_driver.SchDoc, hbridgeB.SchDoc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]
2025-11-03 fix(schematics): schmatics conection was fixed
    problems with conections like VCC, 3.3V, GND and PGND were fixed, problem with SNA, SNB, SNC were also solucionated.
    [bulk_capacitance.SchDoc, gate_driver.SchDoc, hbridgeA.SchDoc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]
2025-11-03 feat(src): Resistances and capacitor schematics was added
    capacitance and resistance references was added to the project in "scr" carpet
    [8-SOIC - ANALOG.PcbLib, C0603 - MURATA.PcbLib, CAP - GENERIC.SchLib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]
2025-11-04 feat(schematic): power input schematic was finished
    [power_input.SchDoc]
2025-11-04 fix(components): schematics for components modification WIP
    modification of the components cause a bug in all schematics WIP
    [bulk_capacitance.SchDoc, gate_driver.SchDoc, hbridgeA.SchDoc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]
2025-11-04 fix(footprint): some footprint was fixed WIP
    fixed footprint component is registered in the excel
    [R0603 - YAGEO.PcbLib, pasive_component.PcbLib, passive components.xlsx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]
2025-11-05 fix(footprint): All resistors and capacitor were fixed
    resistors and capacitors were fixed by hand.
    [pasive_component.PcbLib, passive components.xlsx]
2025-11-05 fix(footprint): all footprint passive components were fixed
    All resistors, capacitors, inductors and diodos were fixed by hand
    [Connectors.PcbLib, pasive_component.PcbLib, passive components.xlsx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]
2025-11-05 fix(footprint):all footprint of component were fixed
    connect the footprint with schematics missing
    [phoenix-c1-pcblib1.PcbLib, phoenix-c1-schlib.SchLib]
2025-11-05 feature(components): schematics and footprints were vinculed
    all the component was vinculed with her fixed-footprint, some detail fixed too
    [passive components.xlsx, phoenix-c1-pcblib1.PcbLib, phoenix-c1-schlib.SchLib]
2025-11-05 feat(schematic): encoder almost finished
    schematic of encoder lacks pull-ups in pins SDA and SCL, pushing now to merge with last branch
    [encoder.SchDoc]
2025-11-05 feat(schematics): enconder FINISH
    it is DONE, DONE, with PULL UP RES 2kohm because YES
    [encoder.SchDoc]
2025-11-05 feat(schematics): some schematics fix WIP
    [bulk_capacitance.SchDoc, gate_driver.SchDoc, hbridgeA.SchDoc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]
2025-11-06 feat(schematic):buck schematics is finish!!
    [power_input.SchDoc]
2025-11-06 fix(schematics): bugs schematics was fixed
    resistance and capacitance
    [bulk_capacitance.SchDoc, encoder.SchDoc, gate_driver.SchDoc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]
2025-11-06 fix(schematics): added some details
    details like names in the schematics was added
    [passive_component.PcbLib, phoenix-c1-pcblib1.PcbLib, phoenix-c1-sch.SchDoc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]
2025-11-06 fix(schematics): All schematics was finished
    Schamatics work almost ready- Annotation, conection, connectors, etc, was finish.
    [Connectors.PcbLib, bulk_capacitance.SchDoc, encoder.SchDoc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]
2025-11-06 feat(PCB): phoenix.pcbdoc was added
    Schematics phoenix-c1 missing for the upload to PCB design
    [phoenix-c1.PcbDoc, phoenix-c1.PrjPcb]
2025-11-06 feat(schematics): final schematics was finished
    the schematic with all the modules was finished
    [bulk_capacitance.SchDoc, encoder.SchDoc, external_ports.SchDoc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]
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2025-11-07 fix(PCB): placement fixed
    [Connectors.PcbLib, bulk_capacitance.SchDoc, encoder.SchDoc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]
2025-11-07 feat(schematic): new shield begin !!
    [Phoenix_Shield.SchDoc]
2025-11-07 fix(PCB): better placements
    [bulk_capacitance.SchDoc, encoder.SchDoc, external_ports.SchDoc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]
2025-11-07 fix(PCB): new rule was added
    [phoenix-c1.PcbDoc]
2025-11-08 fix(PCB): Top layer routing
    first Top layer routing
    [power_input.SchDoc]
2025-11-08 fix(PCB): Top layer routing fixing
2025-11-08 feat(schematics):New shield
    [Phoenix_Shield.SchDoc, phoenix-c1.PrjPcb]
2025-11-08 feat(schematics): new library design arduino_PINS
    [phoenix-c1-schlib.SchLib]
2025-11-08 feat(schematic): new footprint
    [Connectors.PcbLib, phoenix-c1-schlib.SchLib]
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2025-11-09 feat(PCB): Botton Layout V1 version
    the botton layout is so problematic
2025-11-09 fix(PCB): some routes fix
2025-11-09 fix(PCB): Botton Layout was changed
    have to change the placement for improve the routes
2025-11-09 fix(PCB): All layout has been connected
2025-11-10 feat(schematics): fix shield 50%
    [phoenix-c1-schlib.SchLib]
2025-11-11 feat(schematics): shield library 100% and pcb 50%
    [Phoenix_Shield.SchDoc, phoenix-c1-schlib.SchLib]
2025-11-11 feat(PCB): 4 layers was added to the pcb
    [phoenix-c1-schlib.SchLib, phoenix-c1.PrjPcb, power_input.SchDoc]
2025-11-12 fix(PCB): Design Rule check iteration
    a lot of problems were solved using design rule check, the soldermask for the stm32g4 were fixed
    [stm32g4.SchDoc]
2025-11-12 fix(PCB): Vias was tented
    added the rule for tented vias
2025-11-12 feat(schematic): the inductor has been changed
    [passive_component.PcbLib, phoenix-c1-pcblib1.PcbLib, phoenix-c1-schlib.SchLib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]
2025-11-13 feat(PCB): New footprint arduino 25%
    [Arduino_Shield.PcbLib]
2025-11-13 fix(PCB): some issues has been fixed
    Issues like isolated copper or inoperative wiring have yet to be resolved
2025-11-13 fix(PCB): dead copper WIP
2025-11-13 fix(components): components library has been restructurated
    the schematics components library, now footprints library WIP
    [CAP - 0603X473K1RACTU.SchLib, CAP - 0805GC102JAT2A.SchLib, CAP - 0805GC105MAT2A.SchLib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]
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2025-11-14 fix(footprints): library for each footprint component WIP
    various library components has been added to the project WIP
    [40-WQFN - TEXAS.PcbLib, 48-UFQFN - STMicroelectronics.PcbLib, 8-TDFN.PcbLib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]
2025-11-14 fix(footprints): footprints library has been restructurated
    All the footprints components library has been finished
    [8-TDFN - ANALOG.PcbLib, C01005 - MURATA.PcbLib, C0201 - MURATA.PcbLib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]
2025-11-14 fix(schematics): schematics were revinculated to footprints
    all the schematics has been revinculted to footprint respectly
    [C0603 - KEMET.PcbLib, C0603 - TDK.PcbLib, CAP - 0603X473K1RACTU.SchLib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]
2025-11-14 fix(schematics): all schematics has been fixed with the new components
    [Phoenix_Shield.SchDoc, bulk_capacitance.SchDoc, encoder.SchDoc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]
2025-11-14 fix(schematics): ARDUINO_PINS is resurrected!!!
    [CONN - ARDUINO PINS.SchLib]
2025-11-14 fix(schematics): All schemtics grid problems has been solved
    [Phoenix_Shield.SchDoc, bulk_capacitance.SchDoc, encoder.SchDoc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]
2025-11-14 Checkpoint before to "import changes from schematics"
    [stm32g4.SchDoc]
2025-11-14 fix(schematics): annotation ajust
    [bulk_capacitance.SchDoc, encoder.SchDoc, external_ports.SchDoc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]
2025-11-14 fix(PCB): All PCB has been fixed
    no errors founded
    [gate_driver.SchDoc, leds.SchDoc, stm32g4.SchDoc]
2025-11-14 fix(PCB): Some issues has been fixed
2025-11-14 feat(schematics):PCB_library ARDUINO pins finish
    [ARDUINO.PcbLib]
2025-11-15 fix(PCB): Some detail has been fixed
    [bulk_capacitance.SchDoc]
2025-11-15 fix(PCB): Last detail for slikscreen and layers
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2025-12-05 feat(Jobs): gerber files and BOM has been created
    [phoenix-c1.PrjPcb, phoenix-c1.xlsx]
2026-05-28 feat(fw): stm32 y drv8323 footprint has been fixed
    [40-WQFN - TEXAS.PcbLib, 48-UFQFN - STMicroelectronics.PcbLib, phoenix-c1.PcbDoc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]
2026-05-29 fix(hw): power module has been reacomoded
    [Copy of phoenix-c1.PcbDoc, phoenix-c1.PcbDoc, power_input.SchDoc]
2026-05-30 fix(hw): Optional Encoder mode has been rerouted
    [phoenix-c1.PcbDoc, stm32g4.SchDoc]
2026-05-30 feat(hw): new botton silkscreen
    [CONN - TH_UART.PcbLib, L1515 - COILCRAFT.PcbLib, phoenix-c1.PcbDoc]
2026-06-03 variant L1 footprint added
    [IND - LPS4018-333MRC.SchLib, IND - SRN4018-330M.SchLib, L1515 - BURNS.PcbLib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]
2026-06-07 feat(hw): gerber files generated
    [phoenix-c1.GBL, phoenix-c1.GBO, phoenix-c1.GBP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]
2026-06-14 gerber corrected
    [phoenix-c1.GBL, phoenix-c1.GBO, phoenix-c1.GBP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]

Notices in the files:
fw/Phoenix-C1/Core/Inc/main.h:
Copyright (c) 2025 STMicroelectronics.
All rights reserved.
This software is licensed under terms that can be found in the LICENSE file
